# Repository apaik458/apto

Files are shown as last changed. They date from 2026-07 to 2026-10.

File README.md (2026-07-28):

# Apto

Bimanual manipulation platform
* Two 6-DoF arms + two 1-DoF parallel grippers + 1-DoF neck (total 15 DoF)
* Waveshare servos (CF35-12 + ST3025)
* 3D printed parts + aluminium servo frames

<div align="center">
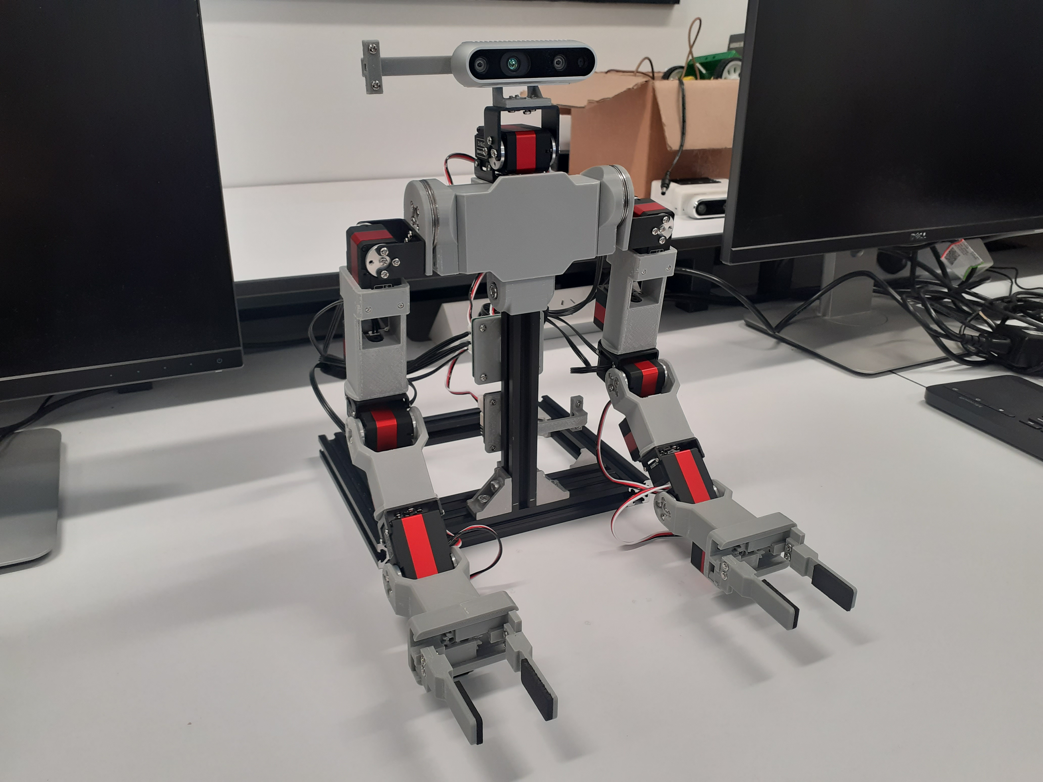
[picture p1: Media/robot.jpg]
    
</div>

## Directory Guide

```
apto/
├── API/                           ## API for controlling robot
│   ├── cfservo_sdk/
│   │   ├── __init__.py
│   │   ├── group_sync_read.py
│   │   ├── group_sync_write.py
│   │   └── ...
│   ├── client.py
│   ├── main.py
│   ├── requirements.txt
│   └── README.md
├── Docs/                          ## Information on constructing robot
│   ├── bill_of_materials.md
│   ├── assembly_instructions.md
│   └── README.md
├── Hardware/                      ## Hardware files for 3D printing and PCB
│   ├── PCB/
│   │   ├── robot_pdb.pro
│   │   └── ...
│   ├── STEP/
│   │   ├── base1.step
│   │   └── ...
│   ├── STL/
│   │   ├── base1.stl
│   │   └── ...
│   └── README.md
├── Media/                         ## Images/GIFs
│   ├── robot.jpg
│   └── robot_sim.png
├── LICENSE
└── README.md
```

## Simulation

Refer to the [apto_sim](https://github.com/apaik458/apto_sim) repo for the Maniskill simulation environment

<div align="center">
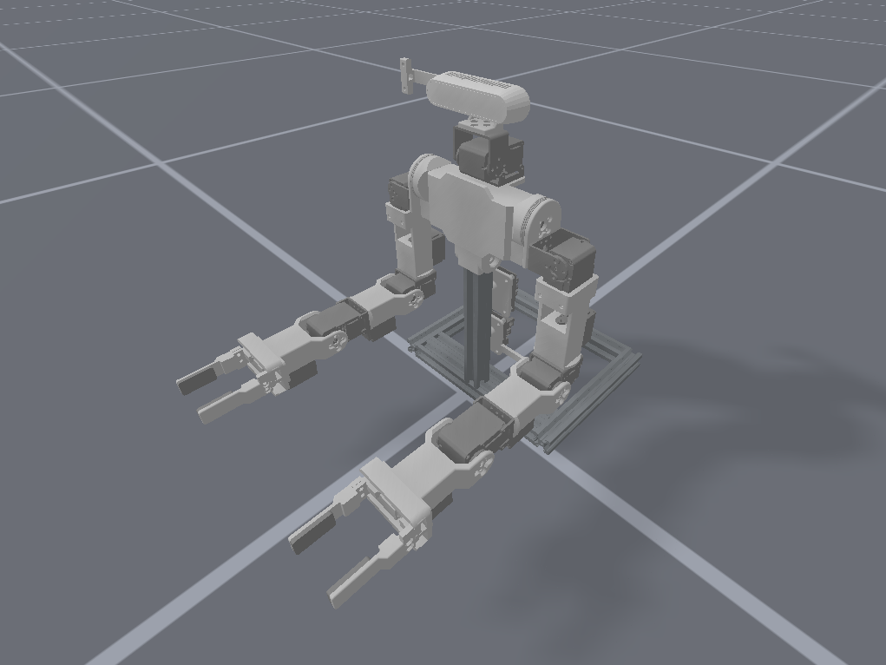
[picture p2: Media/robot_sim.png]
    
</div>

## Acknowledgements

Inspiration and reference from the following projects:
* [Rakuda-2](https://github.com/ROBOTIS-JAPAN-GIT/rakuda2_example)
* [Hitachi Bimanual Robot](https://monoist.itmedia.co.jp/mn/articles/2603/24/news056.html)
* [SO-ARM100](https://github.com/TheRobotStudio/SO-ARM100)
* LEAP Hand ([API](https://github.com/leap-hand/LEAP_Hand_API), [Power distribution board](https://github.com/leap-hand/LEAP_Power))
* [Techniccontroller Parallel Gripper](https://techniccontroller.com/3d-printed-parallel-gripper/)

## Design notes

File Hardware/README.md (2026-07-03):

# Hardware

Files related to physical robot platform

```
Hardware/
├── PCB/    ## PCB files for power distribution board
├── STEP/   ## 3D CAD STEP files
└── STL/    ## 3D CAD STL files
```

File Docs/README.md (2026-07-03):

# Documentation

Information on constructing robot

```
Docs/
├── assembly_instructions.md
└── bill_of_materials.md
```

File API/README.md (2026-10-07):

# API

A Python API for controlling the robot platform
```
API/
├── scservo_sdk/       ## SCServo SDK for FeeTech/Waveshare servos
├── apto_sdk.py        ## Robot platform API
├── main.py            ## Apto SDK usage
├── README.md
└── requirements.txt
```

## Setup

(Optional) Create virtual environment

```bash
conda create -n apto_env python==3.12
```

Install dependencies

```bash
pip install -r requirements.txt
```

## Usage

Run example script to move robot to home pose

```bash
python main.py
```

Note: If getting `Permission denied: '/dev/ttyACM0'` error, change port permission with `sudo chmod a+rw /dev/ttyACM0` command

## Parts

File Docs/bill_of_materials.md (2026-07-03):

# Bill of Materials

Product links are representative; search for similar item from local vendor.

### Servos

| Item | Quantity | Unit Cost (NZD) | Total Cost (NZD) | Product Link  |
| --- | --- | --- | --- | --- |
| Waveshare CF35-12 | 13 | $87.50 | $1092.00 | [Waveshare](https://www.waveshare.com/product/robotics/motors-servos/servos/cf35-12.htm) |
| Waveshare ST3025 | 2 | $140.00 | $275.80 | [Waveshare](https://www.waveshare.com/product/robotics/motors-servos/servos/st3025-servo.htm) |
| Waveshare Serial Bus Servo Driver | 1 | $8.80 | $8.80 | [Waveshare](https://www.waveshare.com/product/robotics/drivers-sensors/drivers/bus-servo-adapter-a.htm) |
| Waveshare Servo Extension Cable | 2 | $3.50 | $7.00 | [Waveshare](https://www.waveshare.com/sr-cable-5264-3pin.htm?sku=34171) |

### Mechanical

| Item | Quantity | Unit Cost (NZD) | Total Cost (NZD) | Product Link  |
| --- | --- | --- | --- | --- |
| 20x20 Anodised Aluminium Extrusion 180mm | 6 | $25.40 | $152.40 | [ALEXCO](https://store.alexco.co.nz/products/20x20-v-slot-aluminium-extrusion-black-anodised) |
| 20 Series Corner Bracket | 6 | $0.80 | $4.80 | [ALEXCO](https://store.alexco.co.nz/products/20-series-standard-corner-bracket) |
| 20 Series T Slot Nut Plate | 18 | $0.40 | $7.20 | [ALEXCO](https://store.alexco.co.nz/collections/20x20-series-v-slot-extrusion-and-hardware/products/20-series-t-slot-nut-plate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) |
| M6 x 10mm Socket Head Cap Screw | 18 | $0.30 | $5.90 | [ALEXCO](https://store.alexco.co.nz/products/cap-screws-stainless-steel-1?variant=40589418364995) |
| M6 Washer | 1 | $4.20 | $4.20 | [Jaycar](https://www.jaycar.co.nz/m6-rack-washer-pack-12/p/HP0322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) |
| AXK2542 Thrust Bearing | 2 | $6.90 | $13.80 | [NZ Miniature Bearings](https://nzminiaturebearings.com/product/25x42x4-mm--AXK2542-Thrust-Bearing.html) |

### Electronics

| Item | Quantity | Unit Cost (NZD) | Total Cost (NZD) | Product Link  |
| --- | --- | --- | --- | --- |
| XT30 Connector | 1 | $4.90 | $4.90 | [Jaycar](https://www.jaycar.co.nz/xt30-2-way-bullet-connectors-plug-socket/p/PT4459) |
| Molex 0022035035 Connector | 16 | $0.30 | $4.90 | [Mouser](https://nz.mouser.com/ProductDetail/Molex/22-03-5035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) |
<!-- | (Camera)                          | 1        | $               | $                | [Waveshare]() | -->

### Total Cost: NZD$1581.70 (USD$903.80)

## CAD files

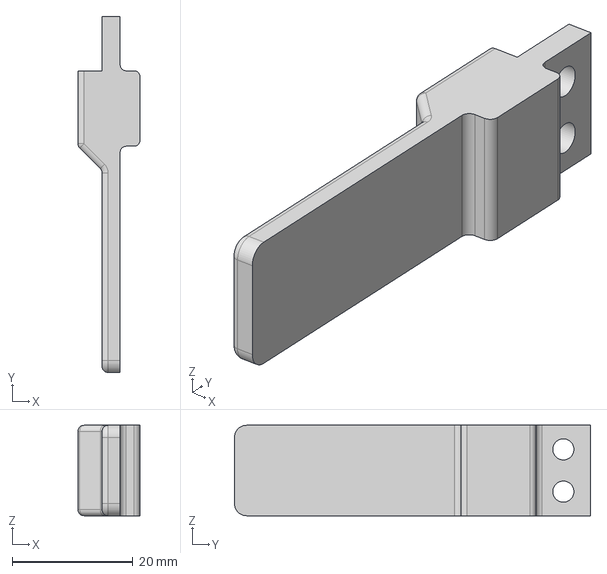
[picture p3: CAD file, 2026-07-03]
Hardware/STEP/Gripper Finger.step
10.3 x 59.0 x 15.0 mm

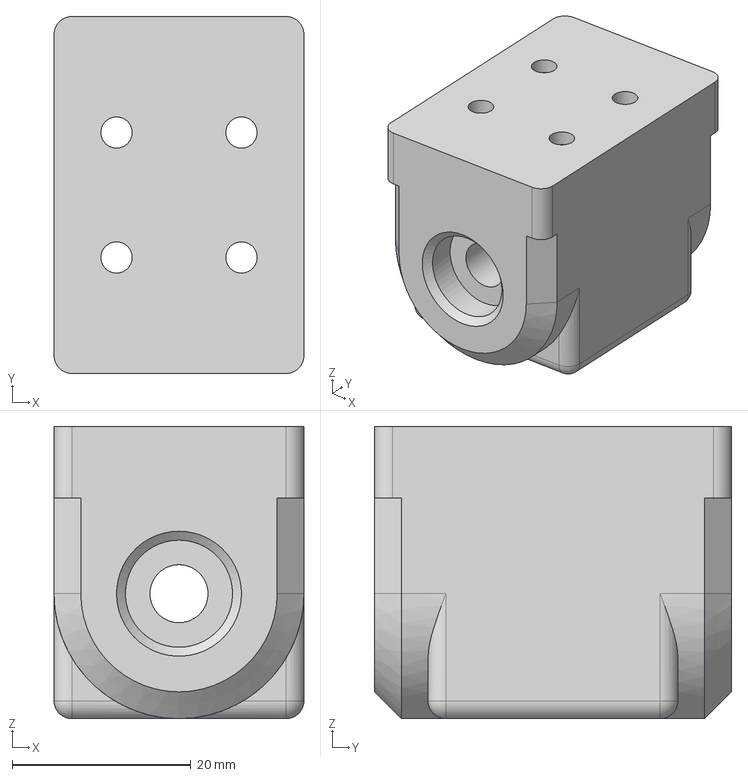
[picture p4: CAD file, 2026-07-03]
Hardware/STEP/base_1.step
28.0 x 40.0 x 32.8 mm

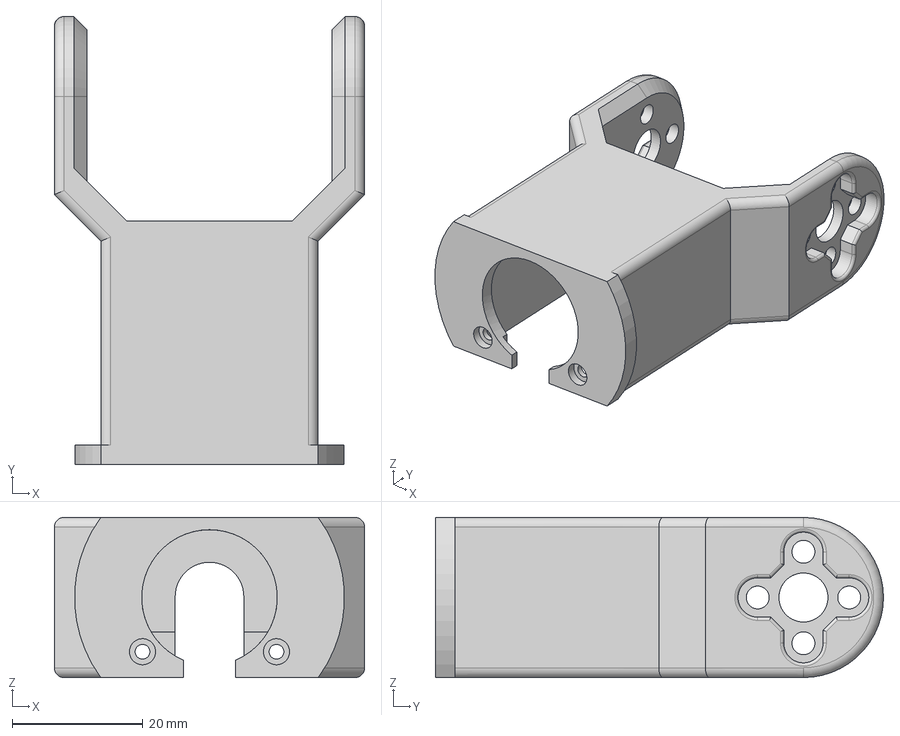
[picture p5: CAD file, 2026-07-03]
Hardware/STEP/arm_4.step
47.5 x 68.6 x 24.5 mm

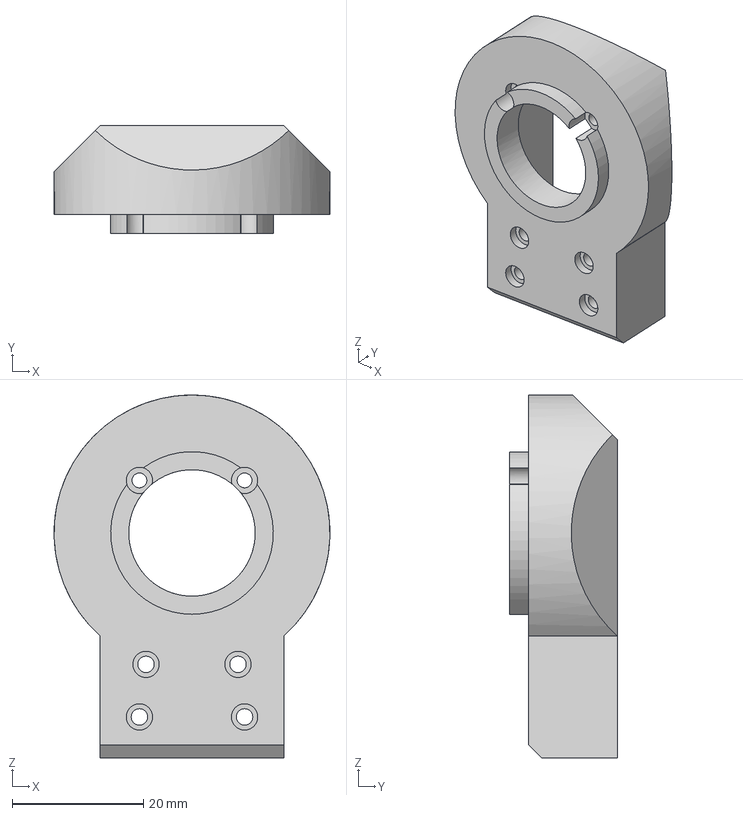
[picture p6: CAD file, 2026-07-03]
Hardware/STEP/arm_1.step
42.0 x 16.4 x 55.2 mm

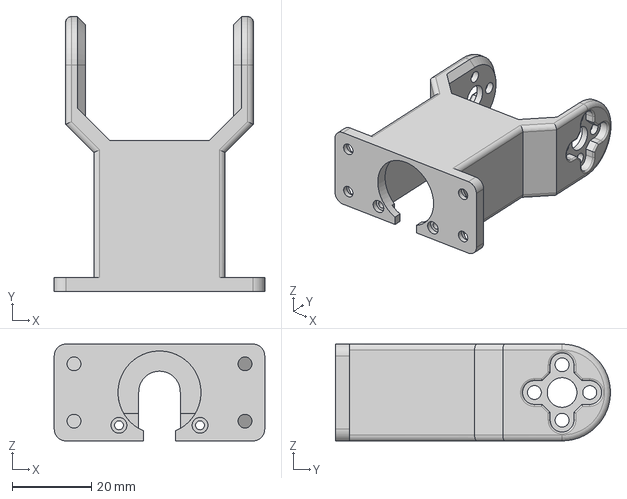
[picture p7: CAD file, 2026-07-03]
Hardware/STEP/Gripper Frame.step
53.2 x 69.6 x 24.5 mm

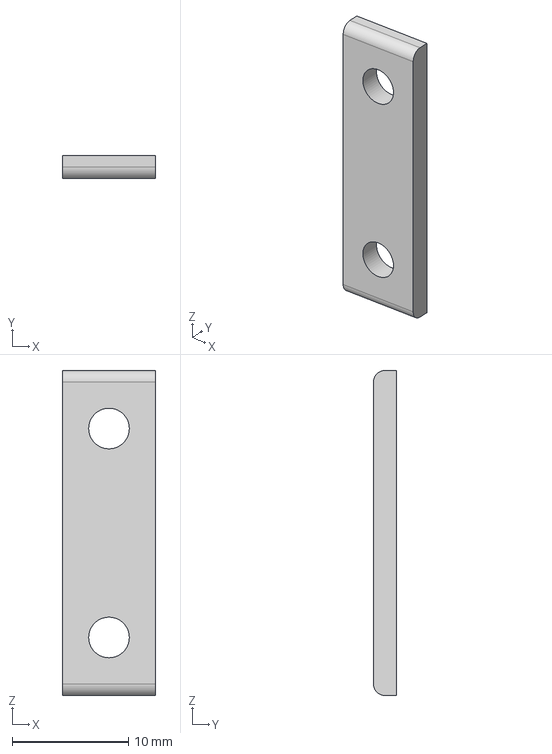
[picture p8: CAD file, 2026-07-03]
Hardware/STEP/driver_board_clamp.step
8.00 x 2.00 x 28.0 mm

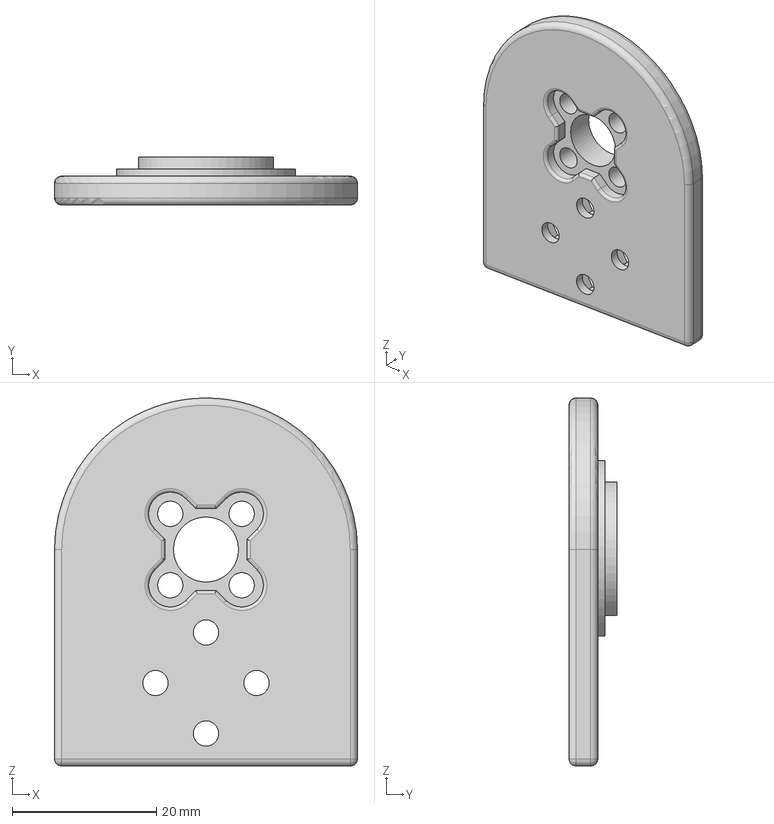
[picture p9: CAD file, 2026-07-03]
Hardware/STEP/arm_2.step
42.0 x 6.65 x 51.0 mm

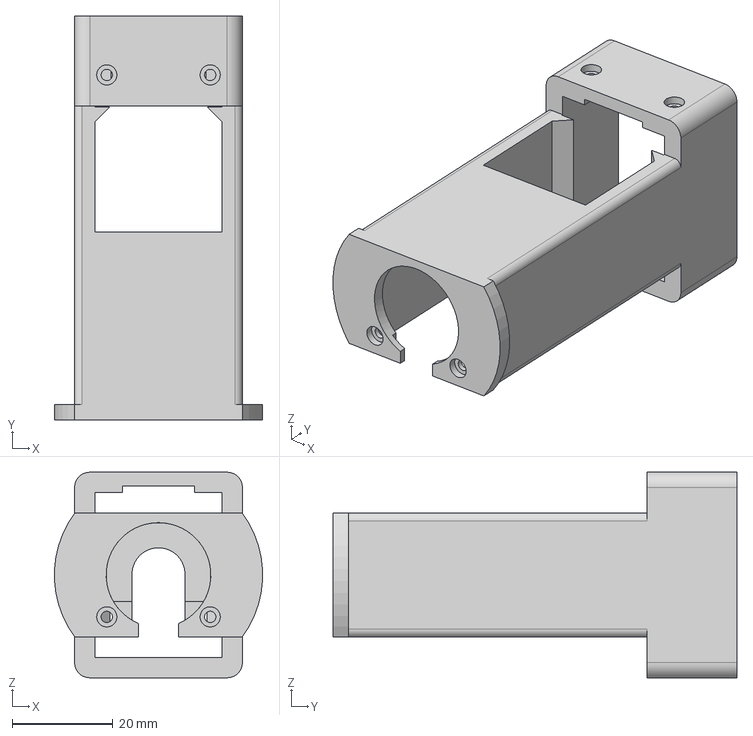
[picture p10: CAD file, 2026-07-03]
Hardware/STEP/arm_3.step
41.2 x 80.0 x 40.8 mm

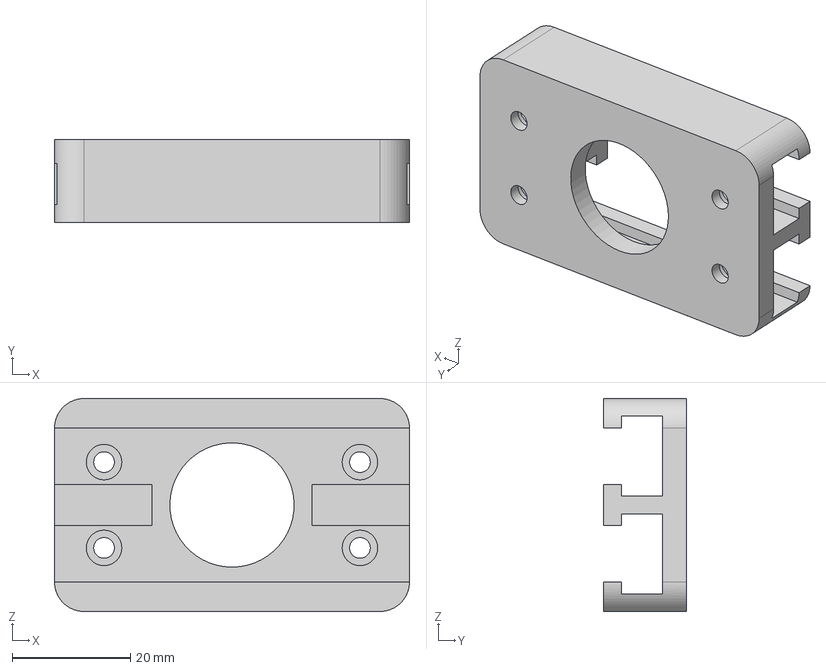
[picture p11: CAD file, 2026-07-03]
Hardware/STEP/Gripper Carrier.step
60.0 x 14.0 x 36.0 mm

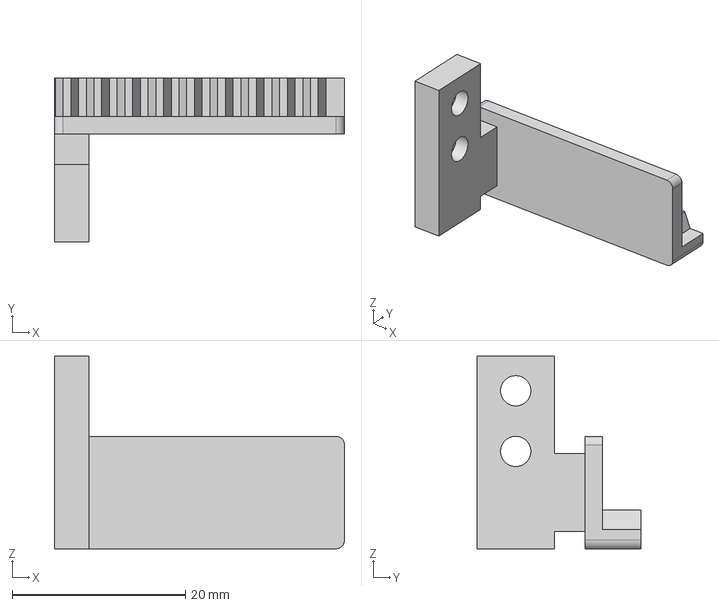
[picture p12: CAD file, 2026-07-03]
Hardware/STEP/Gripper Key.step
33.5 x 19.0 x 22.2 mm

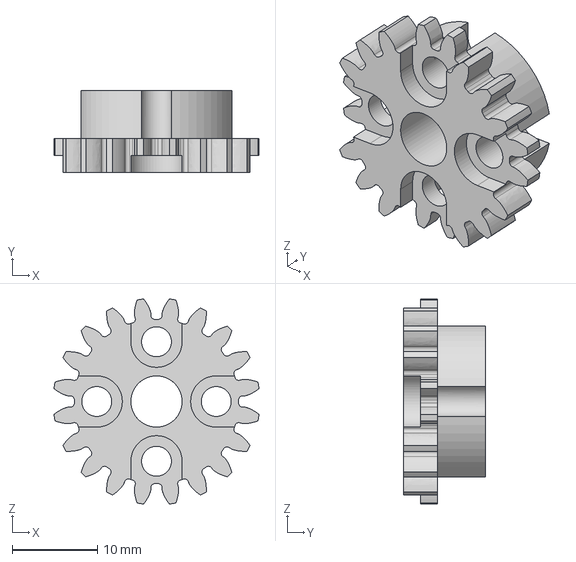
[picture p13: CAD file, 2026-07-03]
Hardware/STEP/Gripper Gear.step
24.0 x 9.65 x 24.0 mm

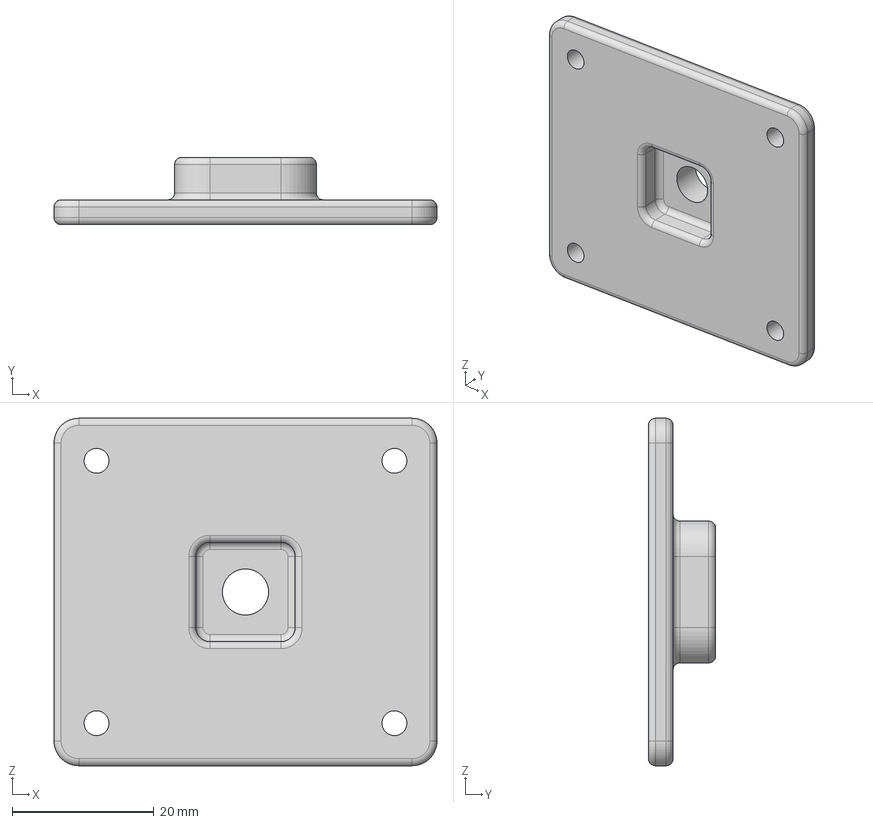
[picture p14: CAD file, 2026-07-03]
Hardware/STEP/power_distribution_board_stand.step
54.0 x 9.50 x 49.0 mm

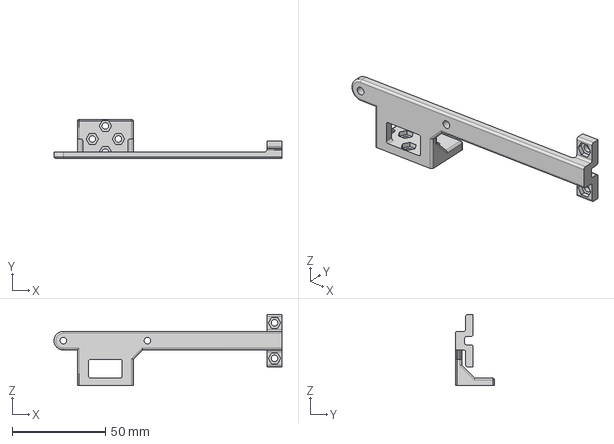
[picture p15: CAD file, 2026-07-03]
Hardware/STEP/base_3.step
122.0 x 21.0 x 38.0 mm

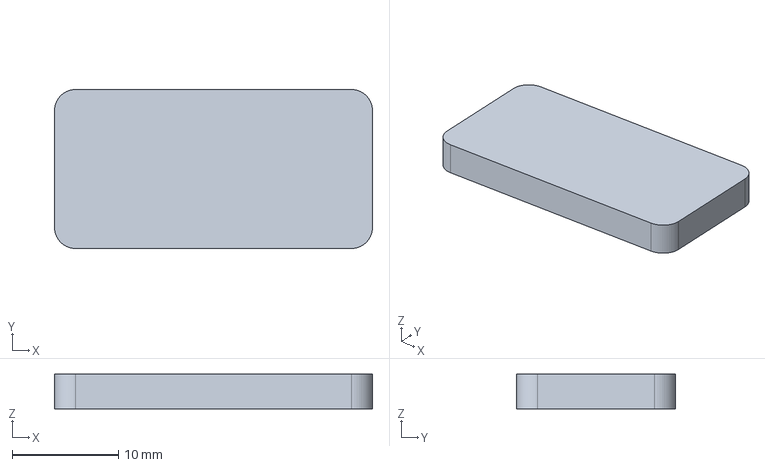
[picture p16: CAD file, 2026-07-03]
Hardware/STEP/Gripper Pad.step
30.0 x 15.0 x 3.30 mm

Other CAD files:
Hardware/STEP/base_2.step
Hardware/STEP/driver_board_stand.step
Hardware/STEP/base_3_clamp.step
Hardware/STL/Gripper Carrier.stl
Hardware/STL/Gripper Finger.stl
Hardware/STL/Gripper Frame.stl
Hardware/STL/Gripper Gear.stl
Hardware/STL/Gripper Key.stl
Hardware/STL/Gripper Pad.stl
Hardware/STL/arm_1.stl
Hardware/STL/arm_2.stl
Hardware/STL/arm_3.stl
Hardware/STL/arm_4.stl
Hardware/STL/base_1.stl
Hardware/STL/base_2.stl
Hardware/STL/base_3.stl
Hardware/STL/base_3_clamp.stl
Hardware/STL/driver_board_clamp.stl
Hardware/STL/driver_board_stand.stl
Hardware/STL/power_distribution_board_stand.stl

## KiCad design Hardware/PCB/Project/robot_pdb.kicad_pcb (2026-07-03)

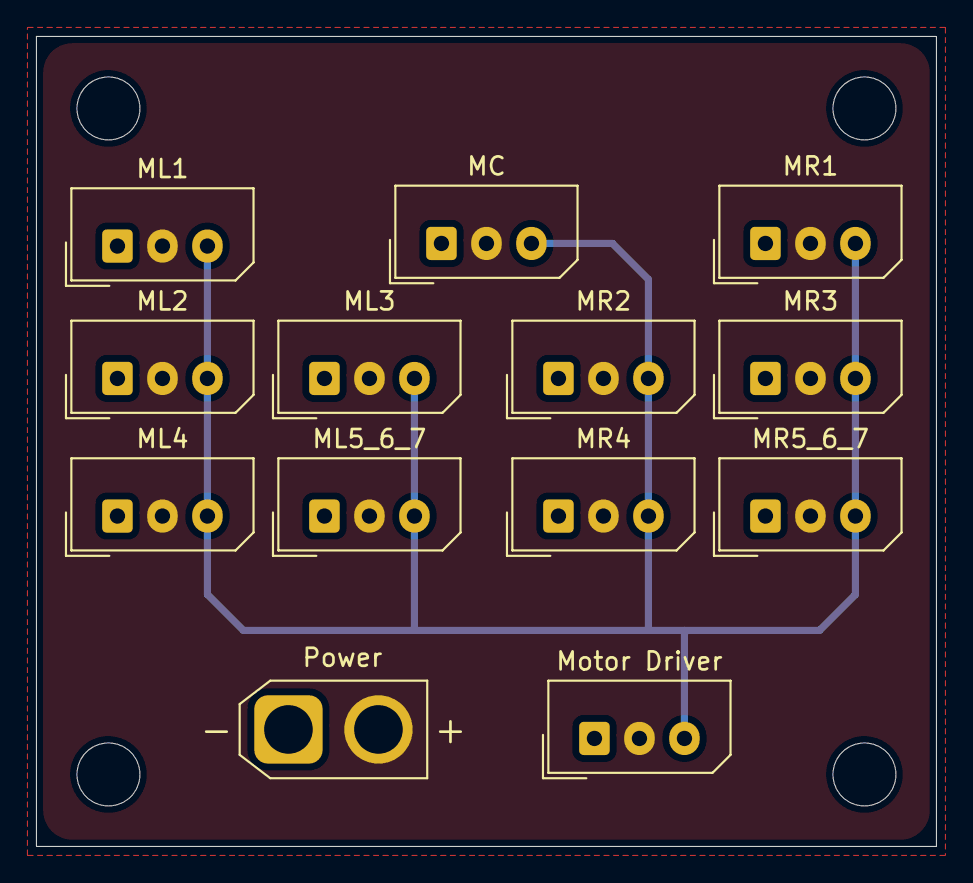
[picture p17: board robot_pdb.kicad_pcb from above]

Board: 2 copper layers, 50.0 x 45.0 mm, 13 parts (0 on the bottom side), 2 nets.

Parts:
MC: Molex_0022035035; Molex_SPOX_5267-03A_1x03_P2.50mm_Vertical
ML1, ML2, ML3, ML4, ML5_6_7: Molex_0022035035; Molex_SPOX_5267-03A_1x03_P2.50mm_Vertical
MR1, MR2, MR3, MR4, MR5_6_7: Molex_0022035035; Molex_SPOX_5267-03A_1x03_P2.50mm_Vertical
Motor Driver: Molex_0022035035; Molex_SPOX_5267-03A_1x03_P2.50mm_Vertical
Power: AMASS_XT30U-M_1x02_P5.0mm_Vertical

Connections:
GND: MC.1, ML1.1, ML2.1, ML3.1, ML4.1, ML5_6_7.1, MR1.1, MR2.1, MR3.1, MR4.1, MR5_6_7.1, Motor Driver.1, Power.1
VCC: MC.2, ML1.2, ML2.2, ML3.2, ML4.2, ML5_6_7.2, MR1.2, MR2.2, MR3.2, MR4.2, MR5_6_7.2, Motor Driver.2, Power.2

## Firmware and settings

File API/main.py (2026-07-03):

import numpy as np
import time

from apto_sdk import *


def main():
    apto_arm = AptoSDK('/dev/ttyACM0', 1000000)
    apto_arm.connect()

    while True:
        apto_arm.set_pose(np.zeros(len(apto_arm.motor_ids)))
        print("Position: " + str(apto_arm.read_pos()))
        time.sleep(0.05)

if __name__ == "__main__":
    main()

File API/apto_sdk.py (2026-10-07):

#!/usr/bin/env python
import atexit
from scservo_sdk import *
import cv2 as cv
import numpy as np

# Memory Table Addresses
HLS_POSITION_LOOP_P     = 21
HLS_POSITION_LOOP_D     = 22
HLS_POSITION_LOOP_I     = 23
HLS_PROTECTION_CURRENT  = 28

# Data Byte Length
LEN_PRESENT_POSITION    = 2
LEN_GOAL_POSITION       = 2
LEN_PRESENT_SPEED       = 2
LEN_GOAL_SPEED          = 2


def cleanup_handler():
    """Cleanup function to ensure motors are disconnected properly."""
    open_clients = list(AptoSDK.OPEN_CLIENTS)
    for open_client in open_clients:
        if open_client.port_handler.is_using:
            print('Forcing client to close.')
        open_client.port_handler.is_using = False
        open_client.disconnect()
    print('Shutting down')

def signed_to_unsigned(value: int, size: int) -> int:
    """Converts the given value to its unsigned representation"""
    if value < 0:
        bit_size = 8 * size
        max_value = (1 << bit_size) - 1
        value = max_value + value
    return value

def unsigned_to_signed(value: int, size: int) -> int:
    """Converts the given value from its unsigned representation"""
    bit_size = 8 * size
    if (value & (1 << (bit_size - 1))) != 0:
        value = -((1 << bit_size) - value)
    return value

## Conversions (0 -> 2048 -> 4096 = -pi -> 0 -> pi), (positive motor rotation = clockwise)
def pos_scale_atv(angle):
    """Converts from joint angles to motor values"""
    return (angle / np.pi + 1) * 2048

def pos_scale_vta(value):
    """Converts from motor values to joint angles"""
    return value * (2 * np.pi / 4096) - np.pi

## Conversions (0 -> 3400 = 0 -> 1.659pi), (50 steps per second = 0.732 RPM)
def vel_scale_stv(angle):
    """Converts from joint speeds to motor values"""
    return (angle / (1.659*np.pi)) * 3400

def vel_scale_vts(value):
    """Converts from motor values to joint speeds"""
    return (value / 3400) * (1.659*np.pi)

## Safety clips all joints so nothing unsafe can happen
def angle_safety_clip(joints):
    min = np.array([0.0,
                    -np.pi/4, -np.pi/10, -np.pi/2, -np.pi/2, -np.pi/2, -np.pi/2, -np.pi/2,
                    -np.pi/4, -np.pi/10, -np.pi/2, -np.pi/2, -np.pi/2, -np.pi/2, -np.pi/2])
    max = np.array([np.pi/2,
                    np.pi/2, np.pi/2, np.pi/2, np.pi/3, np.pi/2, np.pi/2, 0.0,
                    np.pi/2, np.pi/2, np.pi/2, np.pi/3, np.pi/2, np.pi/2, 0.0])
    return np.clip(joints, min, max)

## Adds an offset to the joints to center them properly
def angle_offset(joints):
    value_offset = np.array([62,
                              0,   0,  27, 52,  0, -48, 0,
                             52, -17, -38,  0, 27,   0, 0])
    angle_offset = pos_scale_vta(value_offset) + np.ones(value_offset.shape) * np.pi
    return joints + angle_offset


class AptoSDK:
    """
    Client for communicating with Waveshare motors
    """

    # The currently open clients.
    OPEN_CLIENTS = set()
    
    def __init__(self,
                 port: str = '/dev/ttyACM0',
                 baudrate = 1000000):
        """Initialises a new client"""
        self.motor_ids = [0, 1, 2, 3, 4, 5, 6, 7, 8, 9, 10, 11, 12, 13, 14]
        self.port_name = port
        self.baudrate = baudrate

        self.port_handler = PortHandler(port)
        self.packet_handler = hls(self.port_handler)

        self._pos_reader = AptoPosReader(
            self,
            self.motor_ids
        )

        self._vel_reader = AptoVelReader(
            self,
            self.motor_ids
        )

        self.camera = Camera()

        self._sync_writers = {}
        self.OPEN_CLIENTS.add(self)

        # Parameters
        self.kP = 32               # default PID = 32, 0, 32
        self.kI = 0
        self.kD = 32
        self.curr_lim = 500        # 500 * 0.0065A = 3.25A
        self.moving_speed  = 683   # 683 * (0.732 / 50) = 10RPM
        self.moving_acc    = 25    # 25 * 100 = 2500 steps/s^2
        self.moving_torque = 500   # 500 * 0.0065A = 3.25A

        self.prev_pos = self.pos = self.curr_pos = np.zeros(15)
        self.prev_vel = self.vel = self.curr_vel = np.zeros(15)

    def is_connected(self):
        return self.port_handler.is_open

    def connect(self):
        """Connects to the Waveshare motors"""
        # Typo in port_handler.py, clearPort()?
        # assert not self.is_connected, 'Client is already connected.'

        if self.port_handler.openPort():
            print('Succeeded to open port: %s', self.port_name)
        else:
            raise OSError(
                ('Failed to open port at {} (Check that the device is powered '
                 'on and connected to your computer).').format(self.port_name))

        if self.port_handler.setBaudRate(self.baudrate):
            print('Succeeded to set baudrate to %d', self.baudrate)
        else:
            raise OSError(
                ('Failed to set the baudrate to {} (Ensure that the device was '
                 'configured for this baudrate).').format(self.baudrate))
        
        # Enable motor torques
        self.set_torque_enabled(self.motor_ids, False)

        # Set the default parameters
        self.sync_write(self.motor_ids, np.ones(len(self.motor_ids)) * self.kP, HLS_POSITION_LOOP_P, 1)          # Pgain stiffness
        self.sync_write(self.motor_ids, np.ones(len(self.motor_ids)) * self.kI, HLS_POSITION_LOOP_I, 1)          # Igain
        self.sync_write(self.motor_ids, np.ones(len(self.motor_ids)) * self.kD, HLS_POSITION_LOOP_D, 1)          # Dgain damping
        self.sync_write(self.motor_ids, np.ones(len(self.motor_ids)) * self.curr_lim, HLS_PROTECTION_CURRENT, 2) # Protection current limit
        
        # Set operating mode
        self.set_control_mode("position")
    
    def disconnect(self):
        """Disconnects from the Waveshare device"""
        if not self.is_connected:
            return
        
        if self.port_handler.is_using:
            print('Port handler in use; cannot disconnect.')
            return
        
        # Stop camera streaming
        self.camera.vc.release()

        # Ensure motors are disabled at the end.
        self.set_torque_enabled(self.motor_ids, False, retries=0)
        self.port_handler.closePort()
        if self in self.OPEN_CLIENTS:
            self.OPEN_CLIENTS.remove(self)
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
